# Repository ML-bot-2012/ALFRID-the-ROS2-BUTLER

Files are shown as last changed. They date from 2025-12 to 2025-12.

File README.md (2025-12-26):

FRID - Autonomous SLAM Robot Butler BY 5KROBOTICS and MALHAR LABADE

ALFRID is an autonomous SLAM robot butler inspired by Batman's faithful servant. 

## Overview
Built on ROS2 with dual Raspberry Pi architecture, ALFRID autonomously explores and maps environments in real-time using advanced SLAM algorithms.

## Hardware
- **Main Computer**: Raspberry Pi 5 (Ubuntu 22.04 Jammy)
- **GPIO Controller**: Raspberry Pi 3B+ (Ubuntu 22.04 Jammy)
- **Sensors**: RPLidar A1, 4-channel encoder sensors
- **Motors**: 2x DIY 12V DC Encoder Gear Motors and 1 Micro Servo(Metal Gears)
- **Power**: 12V battery → L298N Motor Driver
- **Custom PCB** for integrated control

## Software Stack
- **Pi5**: ROS2 Jazzy Jalisco - SLAM Toolbox, Nav2, real-time mapping
- **Pi3B+**: ROS2 Humble Hawksbill - motor control, encoder odometry
- **Communication**: WiFi networked via ROS2 Domain ID 0

## Key Features
✅ Real-time SLAM mapping with RPLidar A1
✅ Dual-encoder motor control for navigation
✅ Autonomous exploration and environment mapping
✅ Distributed ROS2 architecture (Pi5 + Pi3B+)
✅ Custom PCB integration

## Installation
```bash
pip3 install alfrid-slam  # Pi5
pip3 install alfrid-gpio  # Pi3B+
```

## Quick Start
**Pi5**: `ros2 launch slam_toolbox online_async_launch.py`
**Pi3B+**: `ros2 launch butler_gpio pi3b_launch.py`

---
Property of 5KROBOTICS & MALHAR LABADE

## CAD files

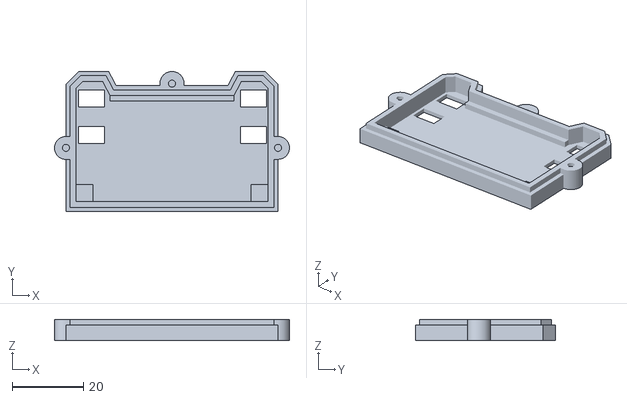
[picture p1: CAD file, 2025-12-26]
POWER SUPPLY CASE bottom.stl
65.8 x 39.2 x 6.00

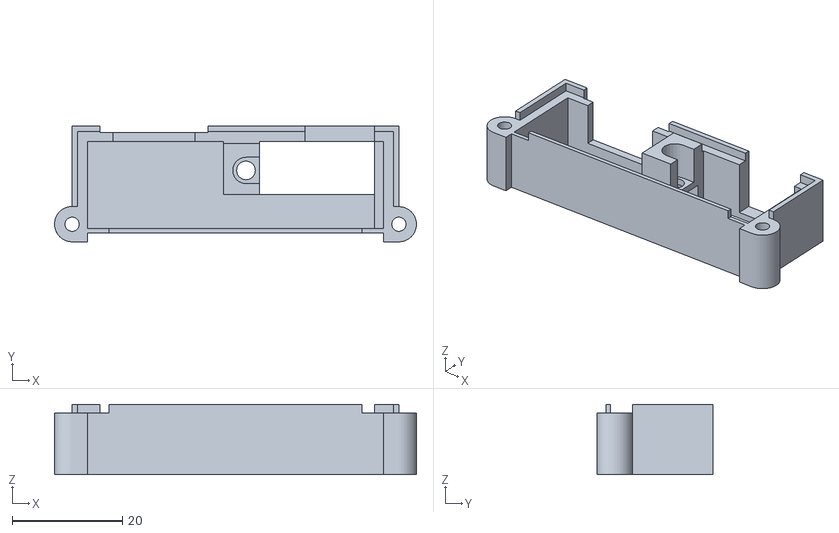
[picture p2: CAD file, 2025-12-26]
POWERSUPPLY CASE top1.stl
65.8 x 21.0 x 12.8

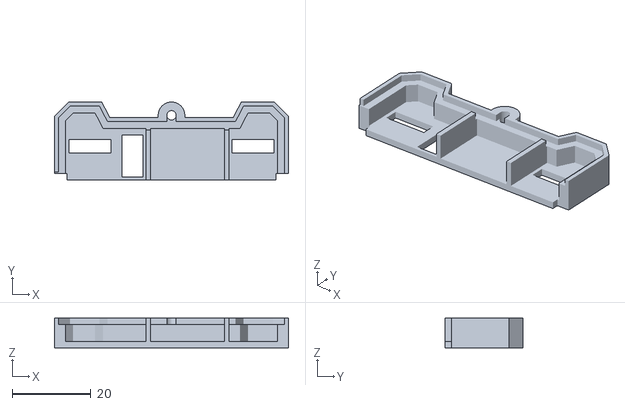
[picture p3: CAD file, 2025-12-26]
POWERSUPPLY CASE top2.stl
59.4 x 19.8 x 7.50

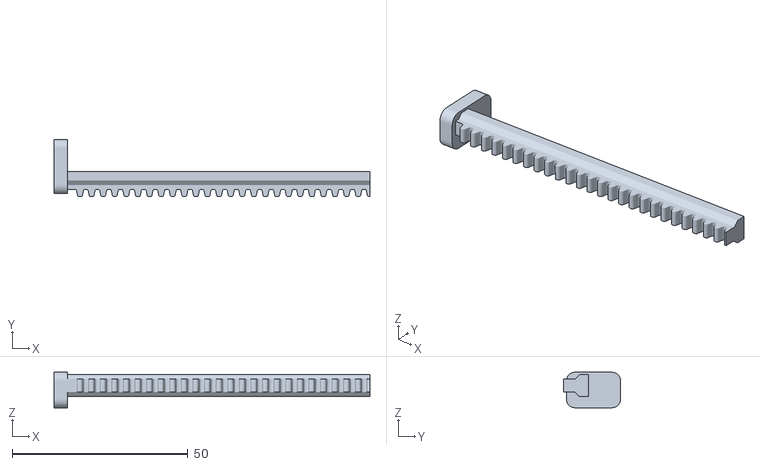
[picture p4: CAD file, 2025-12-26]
RACK.stl
90.0 x 16.3 x 10.2

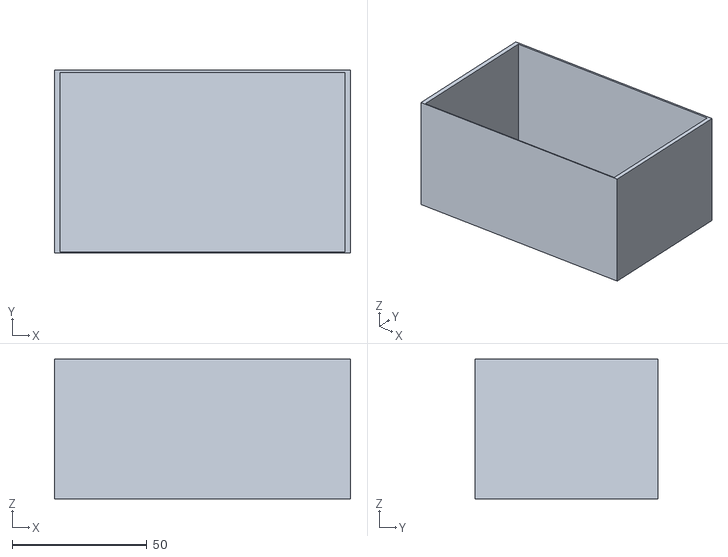
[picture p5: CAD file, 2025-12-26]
FOOD HOLDER.stl
110.0 x 68.0 x 52.0

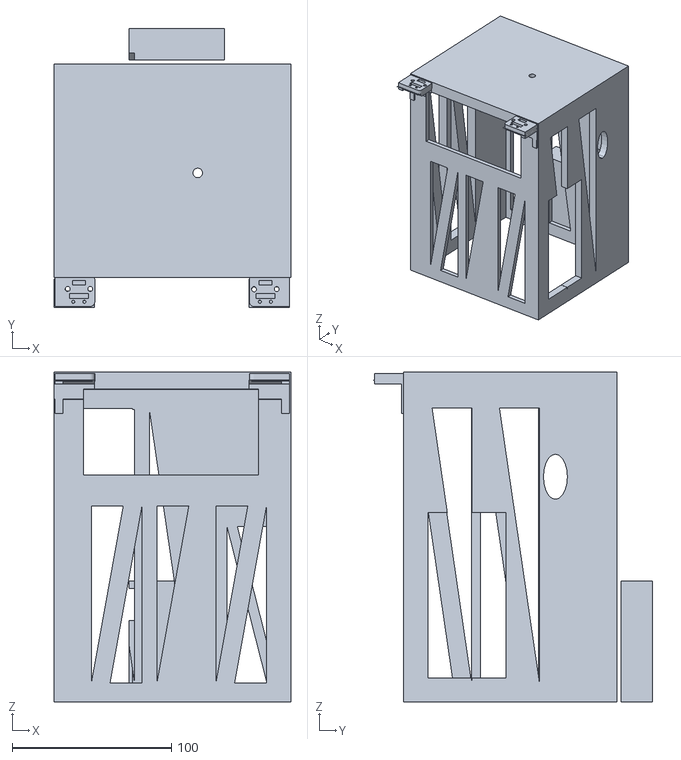
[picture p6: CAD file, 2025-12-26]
chassis-top.stl
148.5 x 175.2 x 207.0

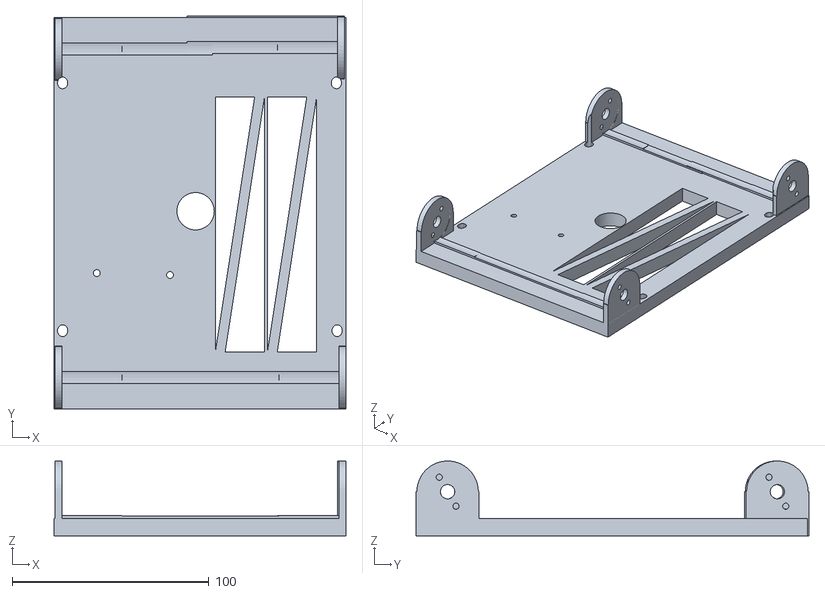
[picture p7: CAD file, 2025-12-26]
motor mounts:bottom chassis plate.stl
148.5 x 199.7 x 38.1

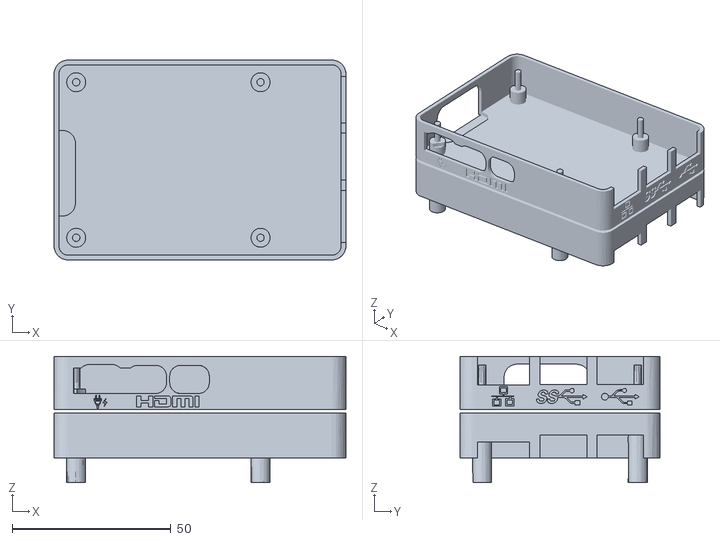
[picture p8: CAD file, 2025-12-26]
pi3Bcase stacked on lid of pi5 case.stl
92.0 x 63.0 x 39.8

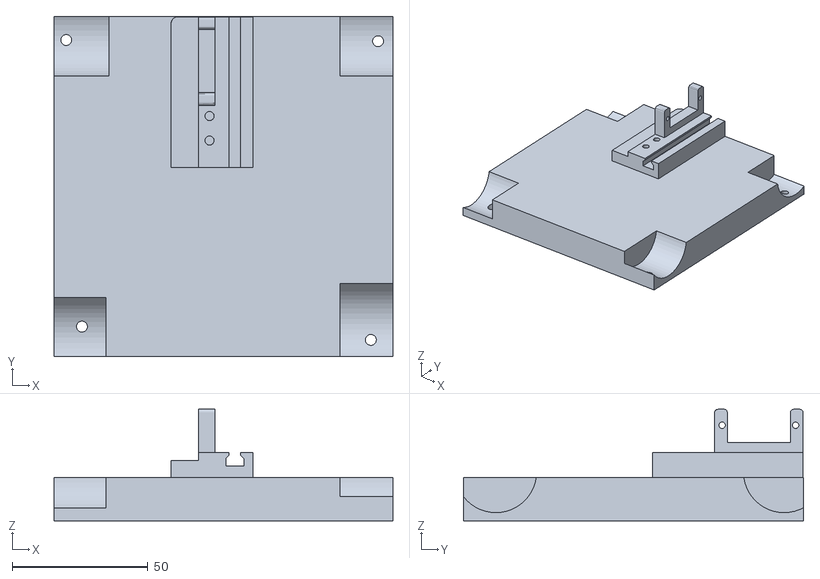
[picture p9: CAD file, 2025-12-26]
Foodbox holder+Micro Servo mount.stl
124.6 x 125.0 x 41.0

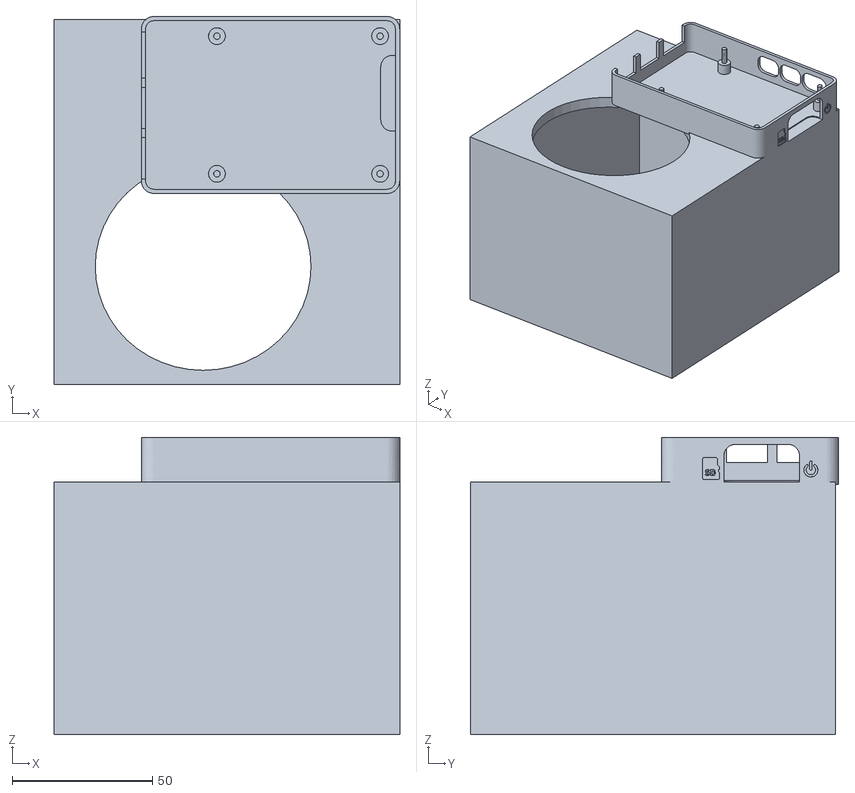
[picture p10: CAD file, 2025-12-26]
wiremanagmentbox+pi5case bottom.stl
123.0 x 131.0 x 105.8

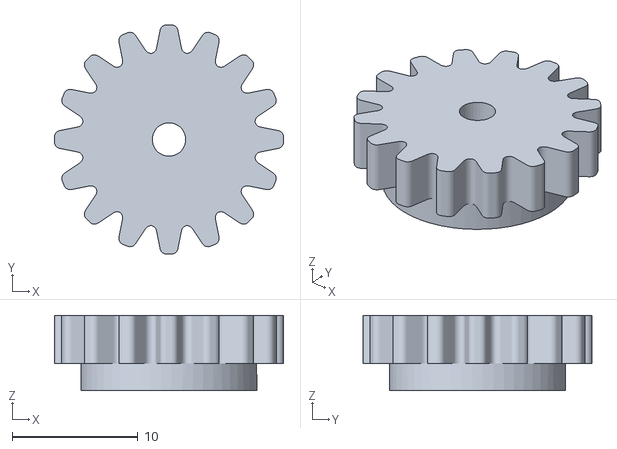
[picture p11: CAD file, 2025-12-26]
pinion_gear_mini_version.stl
18.2 x 18.2 x 5.97

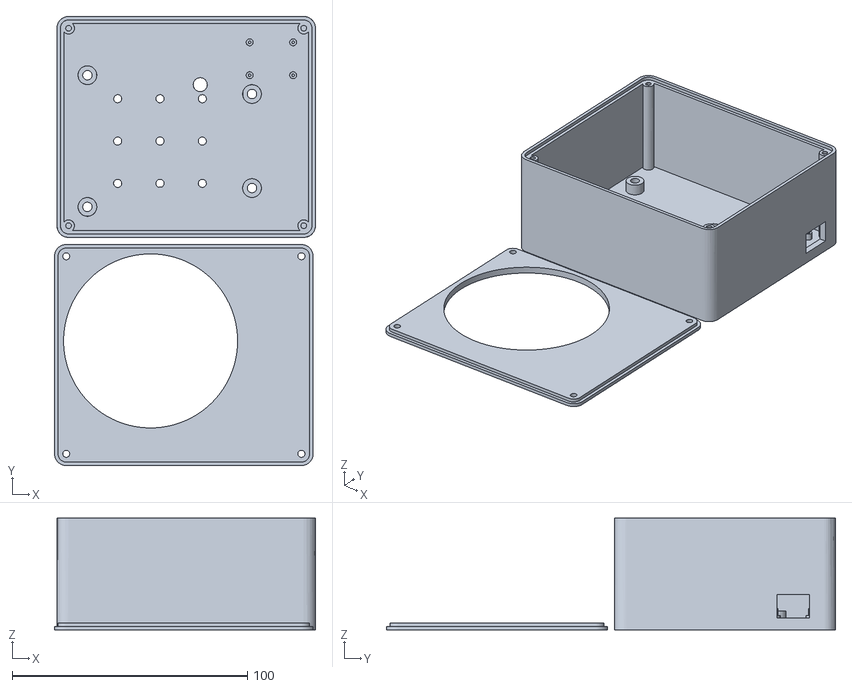
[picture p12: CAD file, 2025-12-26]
M3 screws Lidar mounts.stl
111.0 x 191.0 x 47.5

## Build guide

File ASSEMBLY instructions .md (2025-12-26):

# ALFRID Assembly Guide

## Safety First
- Wear safety glasses when handling tools
- Disconnect 12V battery before working on electronics
- Never force parts - if it doesn't fit, check alignment
- Keep small parts away from children and pets

## Tools Required
- Screwdriver set (Phillips & flat head)
- Wrench/socket set (M3, M4)
- Soldering iron 
- Multimeter for testing
- 3D Printer

## Fasteners & Materials
- M3 and M2 bolts and nuts Set (2 different sets)
- Brass Standoff Set
- Hot Glue Gun (optional)
- 40-100 Jumper wires (male-to-female)
- BreadBoard
- Pi 3B
- Pi 5
- Monitor
- Hdmi cable Pi 3B
- Micro Hdmi Pi 5
- Keyboard
- Mouse
- Rplidar
- USB cables

---

## Part 1: Chassis Assembly

### Step 1.1: Prepare Base Plate
**Components:**
- 1 x Motor
- 1 x Motor Base
- 1 x Tire
- 1 x Coupling
- 1 x Hex Wrench
- 2 x Coupling Screw
- 6 x Small Screw
- 1 x Large Screw
- 3D printed base 

**Instructions:**

1.

6AED5293-7CC7-4317-8657-ADA64E5EFEC3

2.



3.

Screenshot 2025-12-26 at 12 01 37 AM

**Tools Needed:**
- Phillips Head Screwdriver for Large and Small screws (Not INCLUDED with Motors) 
- Hexagonal Allen Key (INCLUDED with Motors)

---

## Part 2: Motor Driver & Power Installation

### Step 2.1: Mount L298N Motor Driver
**Components:**
- L298N Dual H-Bridge
- 2 M3 Phillips Head Screws
- 2 M3 Nuts
**Instructions:**
1.
Screenshot 2025-12-26 at 12 27 16 AM

**Tools Needed:**
- Phillips Head Screwdriver

---

### Step 2.2: Connect Motor Wires to L298N
**Components:**
- Motor wires (Male to Female)
- 

**Wiring:**
LEFT MOTOR → L298N OUT1 & OUT2
RIGHT MOTOR → L298N OUT3 & OUT4
## Motor Control Pins 
LEFT MOTOR:
GPIO 5 = Forward (IN1)
GPIO 25 = Backward (IN2)
GPIO 6 = PWM Speed (ENA)
RIGHT MOTOR:
GPIO 23 = Forward (IN3)
GPIO 24 = Backward (IN4)
GPIO 22 = PWM Speed (ENB)

**Instructions:**

1. Connect All motors to Pi 3B+ 



---

### Step 2.3: Install 12V Battery
**Components:**
-  KBT 12V Battery 70*55*20mm (L*W*T)
- Top Chassis frame (3D printed)

**Instructions:**

1.

Screenshot 2025-12-26 at 12 44 27 AM

**⚠️ WARNING:** Always verify battery polarity before connecting!

---
## Part 3: Encoders

### Step 3.1: Connect Encoder Wires
**Wiring:**
RIGHT FRONT ENCODER:
GPIO 11 = A Channel
GPIO 12 = B Channel
LEFT REAR ENCODER:
GPIO 4  = A Channel
GPIO 8  = B Channel
LEFT FRONT ENCODER:
GPIO 7  = A Channel
GPIO 10 = B Channel
RIGHT REAR ENCODER:
GPIO 15 = A Channel
GPIO 14 = B Channel
**Instructions:**
1.


Connect To PCB or Pi in general



BLACK = ENCODER GND
BLUE = ENCODER POWER(3.3v)
RED = positive
WHITE = negative
GREEN = ENCODER B
YELLOW = ENCODER A
After you connected all of the data pins please connect the Blue wire to an external power supply like a 5V breadboard power supply and Black wire to the GND of the Rasberry Pi 3B and breadboard power supply:



---

## Part 4: RPlidar Installation

### Step 4.1: Attach RPLidar A1
**Components:**
- RPLidar A1
- 3D Printed Mount
- 4xM2 16mm screws
- 4xM2 4mm screws
**Instructions:**
1. Line up the Lidar's Black standoffs to the Mount and screw it in via the M2 screws

2.

 Screenshot 2025-12-26 at 1 23 19 AM

3.

Screenshot 2025-12-26 at 1 25 49 AM

**Tools Needed:**
- Phillips Head Screwdriver
---

## Part 5: Electronics & Wiring

### Step 5.1: Mount Pi Cases
**Components:**
- Pi5 protective case
- Pi3B/3B+ protective case
**Instructions:**
1.

Screenshot 2025-12-26 at 11 12 11 AM

2.

Screenshot 2025-12-26 at 11 16 05 AM

3.

---

### Step 5.2: Connect Motor Control Wires (Pi3B+ to L298N)
**Wiring:**
GPIO 5 (Left FWD) → L298N IN1
GPIO 25 (Left BCK) → L298N IN2
GPIO 6 (Left PWM) → L298N ENA
GPIO 23 (Right FWD) → L298N IN3
GPIO 24 (Right BCK) → L298N IN4
GPIO 22 (Right PWM) → L298N ENB
For negative terminal on L298N please connect the 12v battery GND to Pi3B GND to create a common ground.
(‼️ without it, the motors will not work)

**Instructions:**
1. Wire it up accordingly



### Step 5.3: Connect Encoder Wires (Pi3B+)
**Description:** [Your description here]
**Wiring:**
RIGHT FRONT ENCODER:
GPIO 11 = A Channel
GPIO 12 = B Channel
LEFT REAR ENCODER:
GPIO 4  = A Channel
GPIO 8  = B Channel
LEFT FRONT ENCODER:
GPIO 7  = A Channel
GPIO 10 = B Channel
RIGHT REAR ENCODER:
GPIO 15 = A Channel
GPIO 14 = B Channel

**Instructions:**
1.



Connect the wires to the designated pins 

---

## Part 6: Limit Switches & Servo Installation

### Step 6.1: Mount Limit Switches 
**Components:**
- Left limit switch
- Right limit switch
 **Instructions:**
1.

Screenshot 2025-12-26 at 11 48 39 AM

### Step 6.2: Build Rack & Pinion Mechanism
**Components:**
- Servo motor
- Pinion gear
- Rack gear

**Instructions:**
1.  

Screenshot 2025-12-26 at 10 23 08 AM

2.

Screenshot 2025-12-26 at 10 51 14 AM

3.

Screenshot 2025-12-26 at 10 53 14 AM

---

### Step 6.3: Install Tray Assembly
**Components:**
- Food dispenser tray
- Food Box

**Instructions:**
1. Slide the Box into the hole in the Chassis Top Frame

### Step 6.4: Connect Servo to Pi3B+

**Wiring:**
GPIO 21 → Servo PWM Signal
5V → Servo Power
GND → Servo Ground

**Instructions:**
1. 
Connect Yellow/White to GPIO 21
Connect Red to 5V
Connect Brown/Black to GND

### Part 7: Connect All Chassis Frames together.

### Step 7.1: Slide the Frames into one another
**Components:**
- 4xM3 10-15mm standoffs
- 4xM3 washers
- 4xM3 screws 4mm
**Instructions:**
1.

Screenshot 2025-12-26 at 11 27 01 AM

2.

Screenshot 2025-12-26 at 11 41 16 AM

3. 
Then Flip the whole Robot over and put one M3 screw in evry washer and finally, screw them into the standoffs, create a modular seperation method 

---

### Total Assembly Time
- Estimated: 12 HRS
- Actual: 30 HRS non-stop

### Parts Checklist
- [ ] Chassis assembled
- [ ] Motors installed
- [ ] Wheels attached
- [ ] Encoders installed
- [ ] RPLidar mounted
- [ ] L298N connected
- [ ] Battery installed
- [ ] Limit switches installed
- [ ] Servo & tray installed
- [ ] All wiring complete
- [ ] Cable management done
- [ ] All tests passed
- [ ] Whole mechanical design is done:

ALFRIDpic

## Next Steps After Assembly
1. Verify all connections with multimeter
2. Test each component individually
3. Run integration tests (see QUICKSTART.md)
4. Calibrate motors and encoders
5. Test SLAM mapping
6. Test food dispensing system

---

Property of 5KROBOTICS & MALHAR LABADE © 2025

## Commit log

2025-12-26 Add files via upload
    The pinion and gear for the food tray(STL)
    [gear for pinion.stl, pinion.stl]
2025-12-26 Update and rename README.md to ASSEMBLY instructions .md
2025-12-26 Update ASSEMBLY instructions .md
